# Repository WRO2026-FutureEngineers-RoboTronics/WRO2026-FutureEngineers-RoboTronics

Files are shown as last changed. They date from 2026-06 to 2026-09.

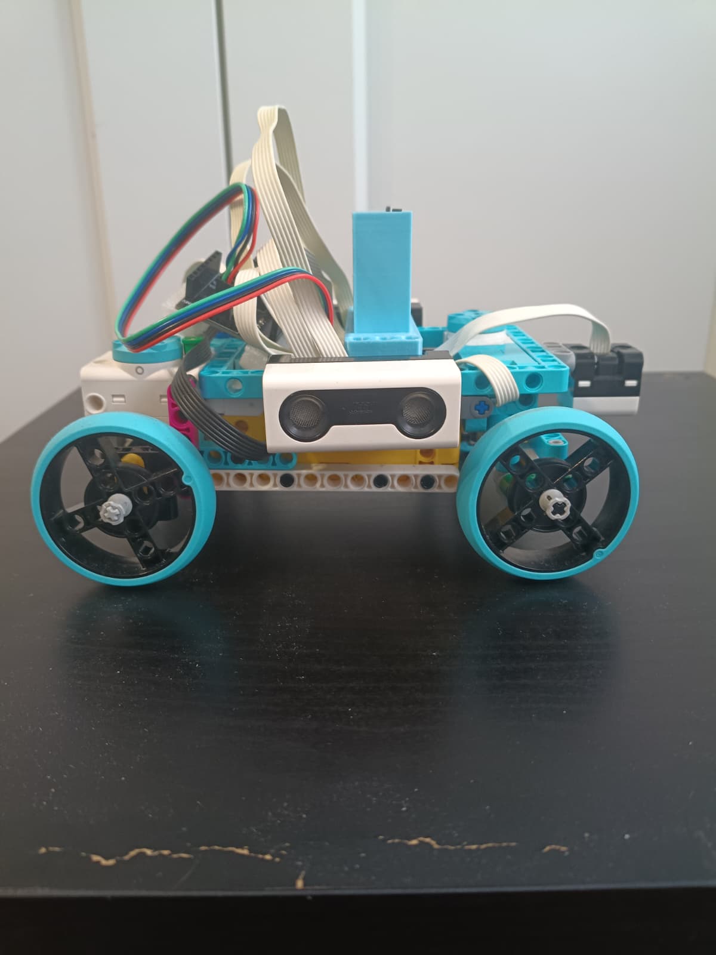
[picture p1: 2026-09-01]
v-photos/V.2/side-V.2.jpeg

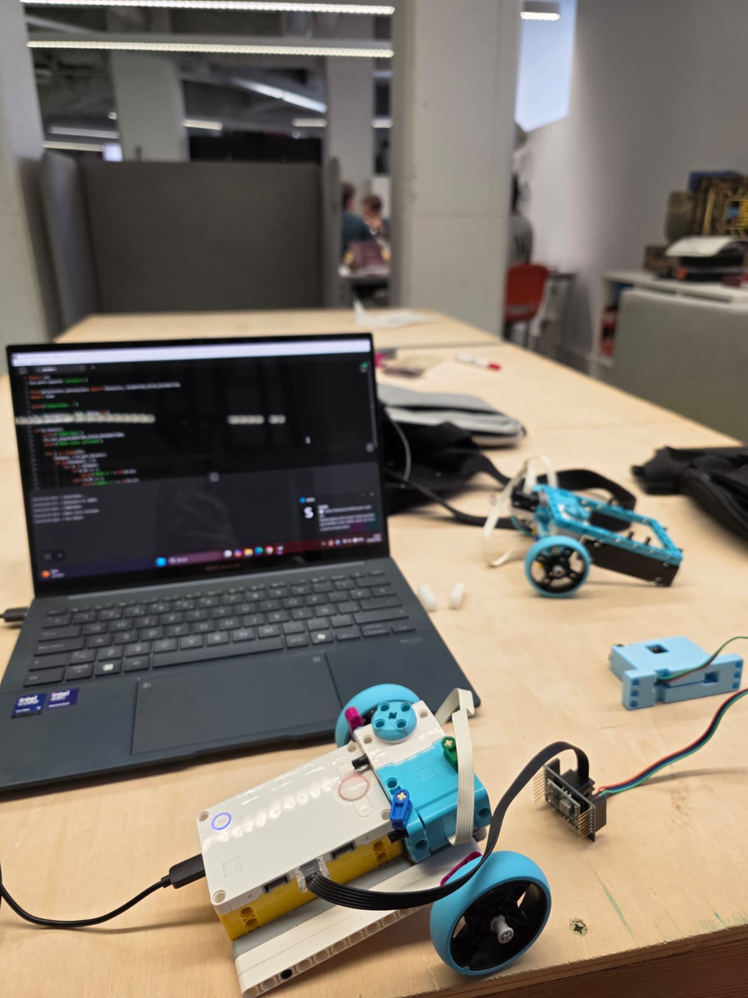
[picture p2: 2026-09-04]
t-photos/robot.jpeg

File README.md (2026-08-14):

# WRO 2026 Future Engineers — RoboTronics

## Team RoboTronics — Basurto, Bilbao, Spain

We are three siblings from Bilbao competing in 
WRO 2026 Future Engineers for the first time, 
after several years in WRO RoboMission.

| Member | Age | Role |
|---|-----|---|
| Sandra García Arias | 20 | Programming and Strategy |
| Oscar García Arias | 16 | Mechanics and Programming |
| Asier García Arias | 16 | Programming and Testing |
| Coach: Edu | — | Guidance and Support |

---

## Our WRO History

| Year | Category | Result |
|---|---|---|
| 2023 | RoboMission Junior | 1st place Euskadi, Top 15 National |
| 2024 | RoboMission Senior | 2nd place Euskadi |
| 2026 | Future Engineers | Qualified for nationals |

---

## The Robot

Built with LEGO Spike Prime with HuskyLens AI camera.
The robot drives autonomously on a 3x3 meter track,
completing 3 laps and stopping in the finish section.

**Platform**: LEGO Spike Prime
**Firmware**: LEGO MINDSTORMS Robot Inventor
**Challenges**: Open Challenge + Obstacle Challenge
**Sensors**: Color sensor + 2 distance sensors + HuskyLens camera
**Motors**: 1 traction + 1 steering (Ackermann)

---

## Documentation

| Section | Content |
|---|---|
| [Mobility and Mechanical Design](src/README.md) | Chassis, steering, drive system |
| [Power and Sensor Architecture](schemes/README.md) | Sensors, connections, power |
| [Software and Strategy](src/README.md) | Code explanation, flow diagram |
| [Vehicle Photos](v-photos/README.md) | Robot from all angles |
| [Team Photos](t-photos/README.md) | Team information |
| [Performance Videos](video/README.md) | YouTube demonstrations |

---

## Port Configuration

| Port | Component | Function |
|---|---|---|
| A | Color sensor | Detects orange/blue lines on floor |
| B | Steering motor | Turns front wheels left/right |
| C | HuskyLens camera | Detects red/green pillars |
| D | Distance sensor | Measures left wall distance |
| E | Distance sensor | Measures right wall distance |
| F | Traction motor | Drives rear wheels forward/backward |

---

## Quick Start — Open Challenge

1. Install pyhuskylens library on hub (see schemes/README.md)
2. Open LEGO MINDSTORMS Robot Inventor app
3. Upload src/open_challenge.py to hub
4. Press center button to turn on
5. Press left button to start
6. Robot completes 3 laps automatically

## Quick Start — Obstacle Challenge

1. Turn on HuskyLens and select Color Recognition mode
2. Point at RED pillar and press learn button (ID 1)
3. Point at GREEN pillar and press learn button (ID 2)
4. Upload src/obstacle_challenge.py to hub
5. Press center button to turn on
6. Press left button to start

---

## Why LEGO Spike Prime

We chose LEGO Spike Prime because we already had
the kit from our previous WRO RoboMission seasons.
This allowed us to focus our time and budget on
learning autonomous navigation rather than on
acquiring new hardware.

The Spike Prime platform provides:
- Reliable MicroPython programming environment
- Built-in rechargeable battery
- Native color and distance sensors
- Sufficient ports for our sensor configuration
- Easy mechanical construction with LEGO pieces

---

## Mechanical Design Summary

### The Main Challenge
The competition rules prohibit differential drive
systems (one motor per side). We had to build a
proper 4-wheeled car with Ackermann steering,
which is the same system used in real cars.

### Our Solution
- **Traction motor (Port F)**: drives both rear
  wheels through a shared axle connected by LEGO
  gears. Both wheels always move together.
- **Steering motor (Port B)**: moves both front
  wheels simultaneously using an Ackermann linkage
  built with LEGO Technic pieces.

### Design Iterations
**Version 1**: Simple chassis without proper
Ackermann geometry. Turning was inconsistent.

**Version 2**: Redesigned front axle with proper
steering linkage. Consistency improved significantly.

**Version 3**: Current version with optimized
sensor placement, HuskyLens camera and better
weight distribution.

---

## Software Summary

### Two Programs

**Program 1 — Open Challenge**
Uses color sensor and distance sensors only.
No camera needed. Completes 3 laps autonomously.

**Program 2 — Obstacle Challenge**
Uses HuskyLens camera to detect red and green pillars.
Passes red pillars on the right and green on the left.
Completes 3 laps and stops in finish section.

### How the Robot Navigates

**Phase 1 — Direction Detection**
The robot moves forward and reads the color sensor.
The first colored line on the track determines the
driving direction for the entire round:
- Orange first → Clockwise → Turn RIGHT at corners
- Blue first → Counterclockwise → Turn LEFT at corners

**Phase 2 — Lap Completion**
Priority system every 50ms:

Priority 1 (Obstacle only): HuskyLens detects pillar
→ steer to correct side to pass it safely.

Priority 2: Color sensor detects a line → turn and
count corner. After 12 corners (4 x 3 laps) → stop.

Priority 3: Side sensors keep robot centered between
walls by comparing left and right distances.

**Phase 3 — Stop**
After 12 corners all motors stop and hub shows OK.

---

## HuskyLens Integration

### Why we added a camera
The Obstacle Challenge requires detecting red and
green pillars placed randomly on the track. The LEGO
color sensor only detects colors at 10cm range which
is too short to react in time.

### HuskyLens solution
The HuskyLens AI camera detects colors from 50-100cm
giving enough time to adjust the robot trajectory.

### Connection
HuskyLens connects via SPIKE-OpenMV breakout board
by Anton's Mindstorms. The board generates stable 5V
from the hub battery to power the camera.

| HuskyLens cable | Breakout Board pin |
|---|---|
| Red | 3V3 |
| Black | GND |
| Green | RX |
| Blue | TX |

Baudrate: 9600 — Protocol: Serial 9600

### Firmware change required
SPIKE 3 firmware does not support serial UART
communication with external devices. We changed
to LEGO MINDSTORMS Robot Inventor firmware which
supports the pyhuskylens library.

---

## Key Engineering Decisions

**Problem: Variable track width**
Inner walls change position each round. Fixed turns
would not work reliably.
Solution: Two side distance sensors measure both
walls and adjust steering automatically.

**Problem: Slow motor response**
run_to_absolute_position() was too slow.
Solution: motor.run() at high speed in deg/sec.

**Problem: Double corner counting**
Each corner has two colored lines close together.
Solution: Track last detected color, only react
when color changes.

**Problem: HuskyLens not connecting**
SPIKE 3 firmware incompatible with pyhuskylens.
Solution: Changed to MINDSTORMS Robot Inventor
firmware and set HuskyLens to Serial 9600 baud.

**Problem: HuskyLens power instability**
HuskyLens firmware 0.5+ draws more current.
Solution: SPIKE-OpenMV breakout board generates
stable 5V from hub battery.

---

## Constraints and Tradeoffs

| Constraint | Decision | Tradeoff |
|---|---|---|
| No differential drive | Ackermann steering | More complex mechanics |
| Only 6 Spike ports | 2 motors + 3 sensors + camera | All ports used |
| SPIKE 3 incompatible | Changed to Robot Inventor | Different programming environment |
| HuskyLens power hungry | SPIKE-OpenMV breakout board | Extra hardware needed |
| First year in category | Simple reliable approach | Less points but more consistent |

---

## How to Reproduce This Robot

### Hardware Required
- 1x LEGO Spike Prime kit (standard grey/yellow box)
- 1x LEGO Spike color sensor
- 2x LEGO Spike distance sensors
- 2x LEGO Spike large motors
- 1x HuskyLens AI camera (DFRobot)
- 1x SPIKE-OpenMV breakout board (Anton's Mindstorms)
- LEGO Technic pieces for chassis

### Firmware Setup
1. Download LEGO MINDSTORMS Robot Inventor app
2. Connect hub via USB
3. Update hub to Robot Inventor firmware

### Library Installation
1. Go to github.com/antonsmindstorms/pyhuskylens
2. Open installer/install_pyhuskylens.py
3. Click Raw → Copy all content
4. Paste in new MINDSTORMS Python program
5. Open console [>_] → Click Play
6. Wait for SUCCESS message
7. Reinstall after every hub firmware update

### Calibration
Run this to check color sensor values:

```python
import sys
sys.path.append('/projects')
from hub import port
import time

while True:
    color = port.A.device.get()
    print("Color: " + str(color))
    time.sleep_ms(200)
```

Place sensor over orange and blue lines.
Note the values and update constants in code.

---

## Current Version — v2.0

### What changed from v1.0
- Added HuskyLens camera for Obstacle Challenge
- Changed firmware to MINDSTORMS Robot Inventor
- Added SPIKE-OpenMV breakout board
- Two separate programs for each challenge

### Development Timeline

| Phase | Status | Description |
|---|---|---|
| v1.0 Mechanics | ✅ Done | Ackermann chassis with Spike |
| v1.0 Open Challenge | ✅ Done | 3 laps with color + distance |
| v1.0 Testing | ✅ Done | Tested at provincial competition |
| Provincial competition | ✅ Done | Qualified for nationals |
| v2.0 Camera research | ✅ Done | HuskyLens selected |
| v2.0 Firmware change | ✅ Done | Robot Inventor firmware |
| v2.0 Camera connected | ✅ Done | Serial 9600 working |
| v2.0 Obstacle Challenge | 🔄 In progress | Testing with pillars |
| National competition | 📅 Planned | September 12-13 2026 |

---

## Lessons Learned

### What we underestimated
- Mechanical complexity of Ackermann steering with LEGO
- SPIKE 3 firmware incompatible with external UART devices
- HuskyLens firmware 0.5+ requires 9600 baud only
- Library must be reinstalled after every hub update

### What worked well
- LEGO Spike as base platform saved time and budget
- Color + distance sensor combination for corner detection
- HuskyLens detects pillars from 50-100cm reliably
- SPIKE-OpenMV breakout board solves power issues

### What we would do differently
- Start with Robot Inventor firmware from the beginning
- Research UART compatibility before buying camera
- Build practice track at home from day one

---

*Team RoboTronics — Basurto, Bilbao, Basque Country, Spain*
*WRO 2026 Future Engineers 2026*

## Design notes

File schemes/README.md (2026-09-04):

# Power and Sensor Architecture

## Power System

The robot runs on the LEGO Spike Prime rechargeable
battery (7.2V Li-Ion). The SPIKE-OpenMV breakout board
generates stable 5V from the hub battery to power the
HuskyLens camera. No external battery is needed.

---

## Port Configuration

| Port | Component | Direction | Purpose |
|---|---|---|---|
| A | Color sensor | Facing DOWN | Detects orange/blue floor lines |
| B | Steering motor | — | Turns front wheels left/right |
| C | HuskyLens camera | Facing FORWARD | Detects red/green pillars |
| D | Distance sensor | Facing LEFT | Measures left wall distance |
| E | Distance sensor | Facing RIGHT | Measures right wall distance |
| F | Traction motor | — | Drives rear wheels forward/backward |

---

## HuskyLens Connection

The HuskyLens connects to the Spike hub via the
SPIKE-OpenMV breakout board by Anton's Mindstorms.

| HuskyLens cable | Breakout Board pin |
|---|---|
| Red | 3V3 |
| Black | GND |
| Green | RX |
| Blue | TX |

**Baudrate**: 9600
**Protocol**: Serial 9600
**Breakout board**: SPIKE-OpenMV by Anton's Mindstorms

The breakout board generates stable 5V from the hub
battery. This is necessary because HuskyLens firmware
0.5+ draws more current than the 3V3 pin can supply.

---

## Sensor Placement Decisions

**Color Sensor — Port A — Facing down**
Mounted at the front of the robot pointing toward the
floor. Placed at the front (not underneath) so it
detects lines earlier, giving the robot more time to
react before the corner.

**HuskyLens Camera — Port C — Facing forward**
Mounted at the front of the robot facing forward.
Detects red and green pillars from 50-100cm distance.
This gives enough time to adjust trajectory before
reaching the pillar.

**Left Distance Sensor — Port D — Facing left**
Mounted on the left side. Measures distance to the
left wall continuously. Used together with the right
sensor to keep the robot centered between walls.

**Right Distance Sensor — Port E — Facing right**
Mounted on the right side. Measures distance to the
right wall continuously. Used together with the left
sensor to keep the robot centered between walls.

---

## Why Two Distance Sensors Instead of Three

In the original design we had three distance sensors
(front, left, right). After adding the HuskyLens camera
in Port C we removed the front sensor since the camera
takes that port.

The front distance sensor is no longer needed because:
- The color sensor detects corners reliably
- The camera provides additional forward awareness
- Two side sensors are sufficient for wall centering

---

## Why HuskyLens Instead of Color Sensor for Pillars

The LEGO Spike color sensor only detects colors at
approximately 10cm range. At competition speed this
is too short to react and adjust trajectory safely.

The HuskyLens detects colors from 50-100cm giving
enough time to plan and execute the avoidance maneuver.

---

## Firmware and Library

**Hub firmware**: LEGO MINDSTORMS Robot Inventor
SPIKE 3 firmware does not support serial UART
communication with external devices. Robot Inventor
firmware is required for HuskyLens communication.

**Library**: pyhuskylens
Install after every hub firmware update:
1. Go to github.com/antonsmindstorms/pyhuskylens
2. Open installer/install_pyhuskylens.py
3. Click Raw → Copy all
4. Paste in MINDSTORMS Python program
5. Open console [>_] → Play → wait for SUCCESS

---

## Connection Photo

Connection

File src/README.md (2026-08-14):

# Software Architecture

## Overview

Two programs for LEGO Spike Prime.
Language: MicroPython (MINDSTORMS Robot Inventor API)
Firmware: LEGO MINDSTORMS Robot Inventor

---

## Port Configuration

| Port | Component | Function |
|---|---|---|
| A | Color sensor | Detects orange/blue lines facing down |
| B | Steering motor | Turns front wheels left/right |
| C | HuskyLens camera | Detects red/green pillars |
| D | Distance sensor | Measures left wall distance |
| E | Distance sensor | Measures right wall distance |
| F | Traction motor | Drives rear wheels forward/backward |

---

## Program 1 — Open Challenge (open_challenge.py)

### Program Phases

**Phase 1 — Direction Detection**
Robot moves forward and reads color sensor.
First colored line determines driving direction:
- Orange → Clockwise → Turn RIGHT
- Blue → Counterclockwise → Turn LEFT

**Phase 2 — Lap Completion**
Robot completes 3 laps using priority system:

Priority 1: Color line detected → turn and count corner
Priority 2: Center between walls using side sensors

**Phase 3 — Stop**
After 12 corners (4 x 3 laps) all motors stop.
Hub displays OK.

### Key Parameters

| Parameter | Value | Description |
|---|---|---|
| VELOCIDAD_TRACCION | 800 | Forward speed in deg/sec |
| VELOCIDAD_DIRECCION | 400 | Steering speed in deg/sec |
| GIRO_SUAVE | 200 | Gentle steering for centering |
| MARGEN_CENTRO | 50 | Centering tolerance in mm |

### How to Upload

1. Open LEGO MINDSTORMS Robot Inventor app
2. Connect hub via USB
3. Create new Python program
4. Copy open_challenge.py content
5. Open console [>_] and click Play

### How to Run

1. Press center button to turn on hub
2. Hub shows ? — waiting for start
3. Press LEFT button to start
4. Robot detects direction automatically
5. Completes 3 laps and shows OK

---

## Program 2 — Obstacle Challenge (obstacle_challenge.py)

### Program Phases

**Phase 1 — Direction Detection**
Same as Open Challenge. Color sensor detects first
line and sets driving direction for entire round.

**Phase 2 — Lap Completion**
Robot completes 3 laps using priority system:

Priority 1: HuskyLens detects RED pillar (ID 1)
→ steer right to pass on the right side

Priority 1: HuskyLens detects GREEN pillar (ID 2)
→ steer left to pass on the left side

Priority 2: Color line detected → turn and count corner

Priority 3: Center between walls using side sensors

**Phase 3 — Stop**
After 12 corners all motors stop. Hub displays OK.

### HuskyLens Setup Before Each Round

1. Turn on HuskyLens
2. Select Color Recognition mode
3. Point at RED pillar → press learn button → ID 1
4. Point at GREEN pillar → press learn button → ID 2
5. Save to HuskyLens memory

### Key Parameters

| Parameter | Value | Description |
|---|---|---|
| VELOCIDAD_TRACCION | 800 | Forward speed in deg/sec |
| VELOCIDAD_DIRECCION | 400 | Steering speed in deg/sec |
| GIRO_CAMARA | 300 | Steering speed when avoiding pillar |
| GIRO_SUAVE | 200 | Gentle steering for centering |
| MARGEN_CENTRO | 50 | Centering tolerance in mm |

---

## Problems Solved During Development

**Problem 1 — Slow movement**
run_to_absolute_position() was too slow and jerky.
Solution: motor.run() at high speed in deg/sec.

**Problem 2 — Double corner counting**
Two lines per corner caused double counting.
Solution: Track last detected color, only react on change.

**Problem 3 — First corner missed**
Robot detected direction but did not turn at first corner.
Solution: Direction detection and turning unified into
one single event.

**Problem 4 — Variable track width**
Inner walls change position each round.
Solution: Two side distance sensors center robot
automatically regardless of wall position.

**Problem 5 — Orange not detected**
Color sensor returned -1 for orange lines.
Solution: Tested RGBI mode. Confirmed color values
on real competition track.

**Problem 6 — HuskyLens not connecting**
SPIKE 3 firmware incompatible with pyhuskylens library.
Solution: Changed hub firmware to LEGO MINDSTORMS
Robot Inventor which supports serial UART communication.

**Problem 7 — HuskyLens baudrate**
HuskyLens firmware 0.5+ does not support 115200 baud.
Solution: Set HuskyLens to Serial 9600 and use
baudrate=9600 in pyhuskylens library.

**Problem 8 — Library disappears after hub update**
Every hub firmware update deletes installed libraries.
Solution: Save installer script on computer and
reinstall after every hub update. Takes 1 minute.

---

## Library Installation

Install pyhuskylens after every hub firmware update:

1. Go to github.com/antonsmindstorms/pyhuskylens
2. Open installer/install_pyhuskylens.py
3. Click Raw → Copy all content
4. Paste in new MINDSTORMS Python program
5. Open console [>_] → Click Play
6. Wait for SUCCESS message

---

## Color Sensor Calibration

Run this to check color sensor values on real track:

```python
from hub import port
import time

while True:
    color = port.A.device.get()
    print("Color: " + str(color))
    time.sleep_ms(200)
```

Place sensor over each color and note values.
Update color constants in code accordingly.

---

## HuskyLens Test Code

Run this to verify HuskyLens connection:

```python
import sys
sys.path.append('/projects')

from pyhuskylens.pyhuskylens import HuskyLens, ALGORITHM_COLOR_RECOGNITION
from hub import port
import time

hl = HuskyLens(port.C, 9600)
time.sleep_ms(2000)

if hl.knock():
    print("CONNECTED!")
    hl.set_alg(ALGORITHM_COLOR_RECOGNITION)
    for i in range(20):
        blocks = hl.get_blocks()
        for b in blocks:
            print("ID:" + str(b.ID) + " x:" + str(b.x))
        time.sleep_ms(500)
else:
    print("Not connected")
```

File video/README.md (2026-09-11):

# Performance Videos

## Open Challenge

Link: [Ver vídeo](https://drive.google.com/file/d/11W35wcra7jwLRkpNSX1HWaoFJbyygJHc/view?usp=sharing)
Link: [Ver vídeo ronda completa](https://drive.google.com/file/d/15G5jBhhnpxqICxf_McOHF0fIDBWsvKSB/view?usp=sharing)

The video shows the robot completing 3 laps 
autonomously on the WRO 2026 track, detecting 
the driving direction automatically and stopping 
in the finish section.

Minimum duration: 30 seconds as required by rules.

## Obstacle Challenge

Link: [To be added after recording]

The video will show the robot completing 3 laps 
while detecting and avoiding red and green pillars.

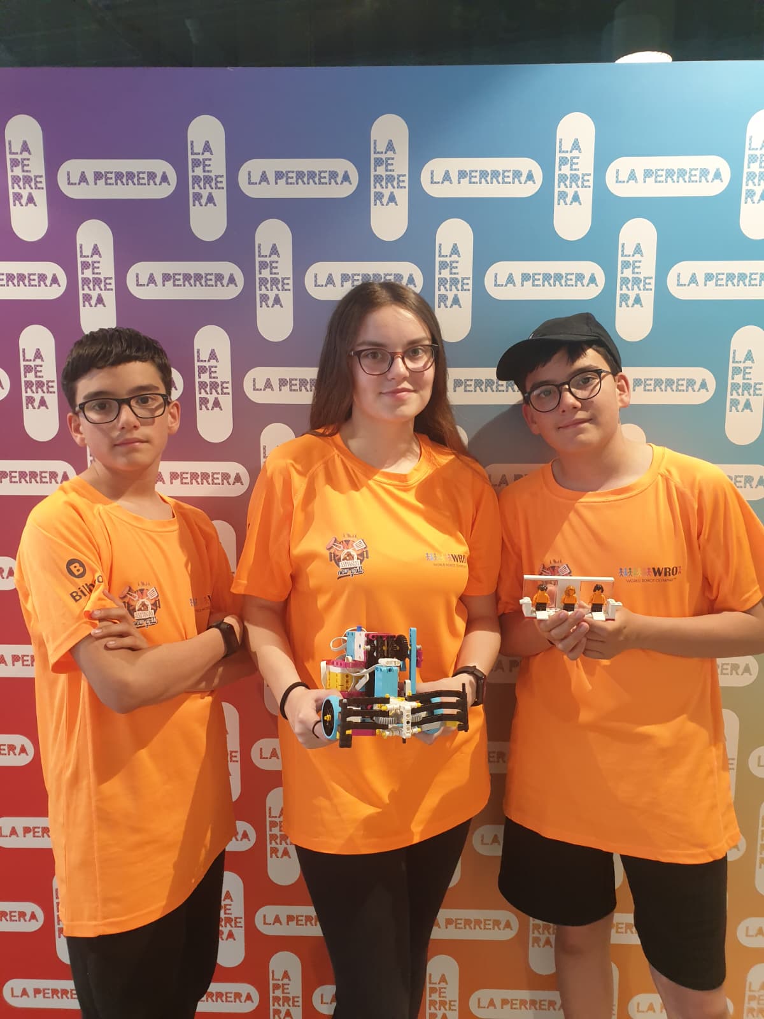
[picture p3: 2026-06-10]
t-photos/img_team.jpeg

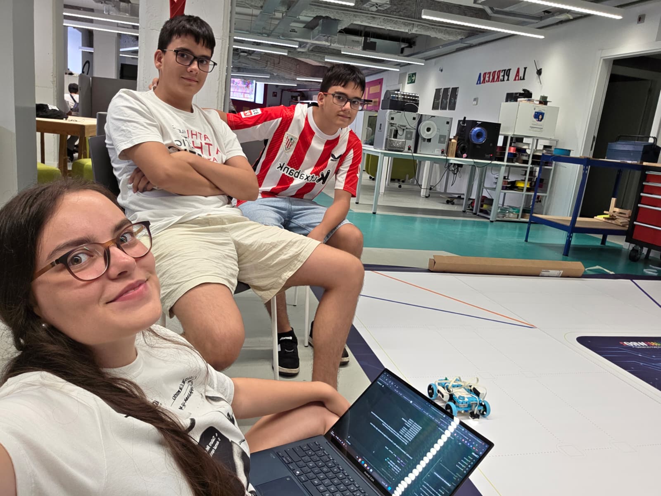
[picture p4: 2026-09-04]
t-photos/img_new.jpeg

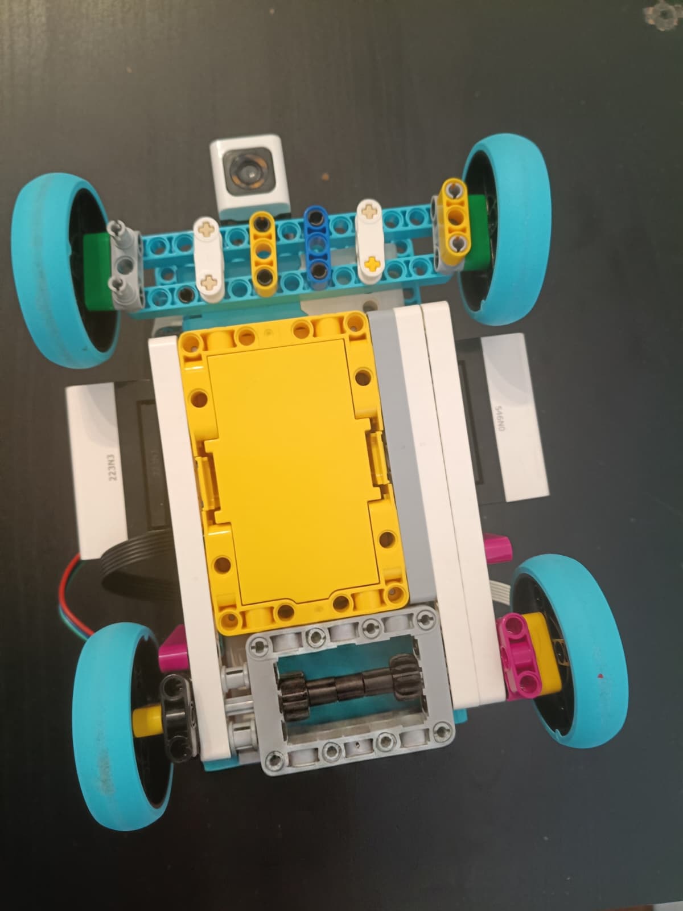
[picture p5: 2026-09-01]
v-photos/V.2/bottom-V.2.jpeg

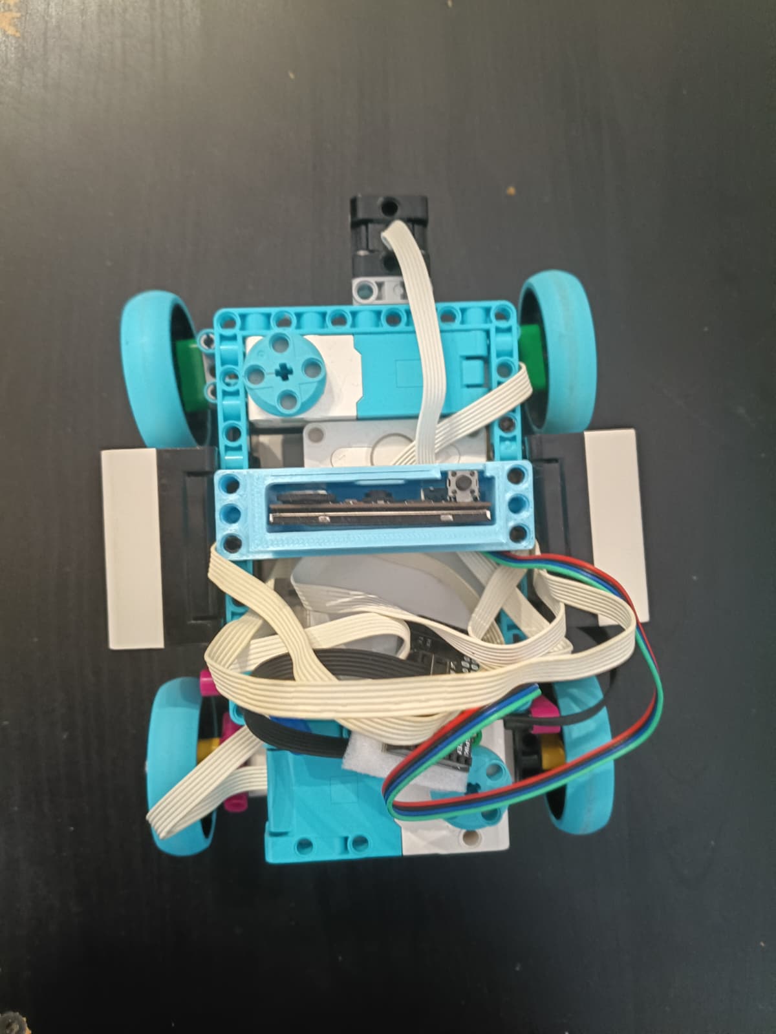
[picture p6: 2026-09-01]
v-photos/V.2/top-V.2.jpeg

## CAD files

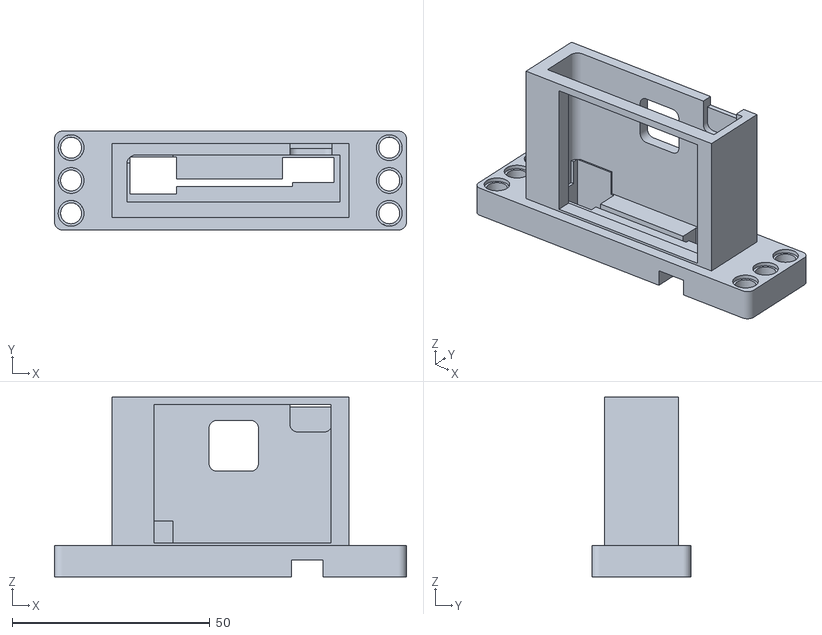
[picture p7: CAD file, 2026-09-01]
HUSKYLENS/HUSKYLENS_case_for_LEGO_CandyDance.stl
89.0 x 25.0 x 45.5
